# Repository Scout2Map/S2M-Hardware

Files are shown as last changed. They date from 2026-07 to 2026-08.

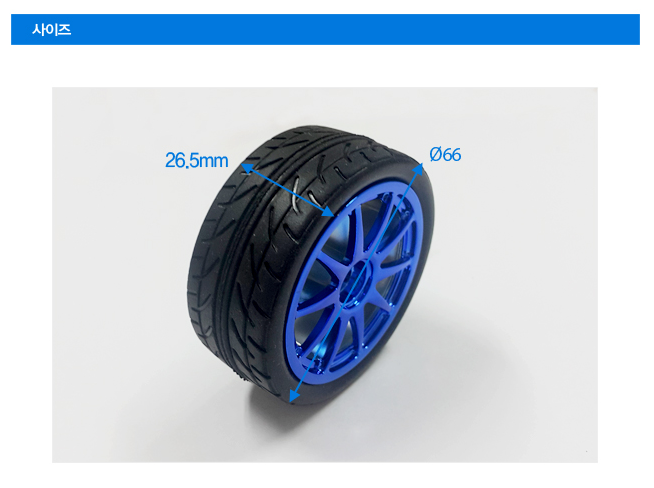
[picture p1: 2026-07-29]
electronics/Offroad 66pi Wheel.png

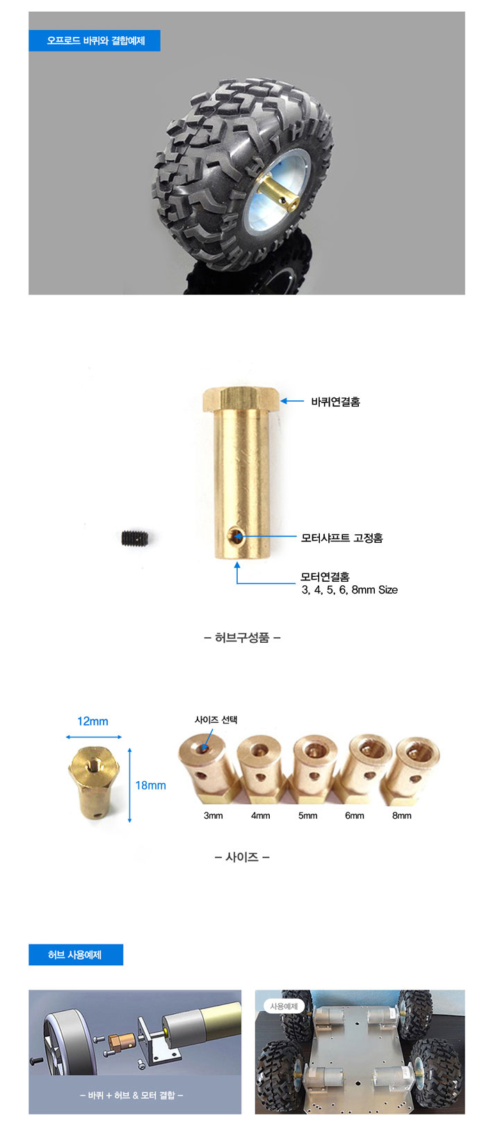
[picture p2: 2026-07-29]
electronics/Motor Hex Hub.png

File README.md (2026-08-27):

# S2M-Hardware

**Scout2Map** — 다중 센서 기반 환경 적응형 정찰 UGV의 하드웨어 설계 자료 저장소.

전자 부품 및 회로 정보는 [`electronics`](./electronics), 차체 설계 자료는 [`mechanical`](./mechanical), ROS2/Gazebo 시뮬레이션용 URDF-xacro 모델은 [`UGV_description`](./UGV_description)에 있다.

## 폴더 구조

```
S2M-Hardware/
├── electronics/            # 전자 부품 스펙, 회로도, 핀맵
├── mechanical/              # 차체 설계 도면, 가공 파일
├── UGV_description/         # ROS2 패키지: URDF-xacro 모델 + 시뮬레이션 에셋
│   ├── package.xml
│   ├── CMakeLists.txt
│   ├── urdf/
│   │   └── scout2map.urdf.xacro   # 로봇 모델 본체
│   ├── config/
│   │   └── bridge.yaml            # gz ↔ ROS2 토픽 브릿지 설정
│   ├── worlds/
│   │   ├── slip_test.world.sdf    # 요철·슬립 테스트용 월드
│   │   └── bump_field.png         # 요철 지형용 heightmap 이미지
│   └── launch/
│       ├── spawn_robot.launch.py       # 로봇 스폰 + robot_state_publisher + 브릿지
│       └── slip_test_world.launch.py   # slip_test 월드 실행
└── README.md
```

`UGV_description`은 실제 차체 치수를 기반으로 한 URDF-xacro 모델과, 이를 Gazebo에서 바로 돌려볼 수 있는 launch/world 파일 일체를 담은 독립 ROS2 패키지다. 디렉터리명은 `UGV_description`이지만 `package.xml` 상의 ROS2 패키지 이름은 `s2m_description`이다.

---

## 사용법 (UGV_description)

### 1. 워크스페이스에 배치 및 빌드

```bash
ln -s ~/S2M-Hardware/UGV_description ~/scout_sim_ws/src/UGV_description
cd ~/scout_sim_ws
colcon build --packages-select s2m_description
source install/setup.bash
```

### 2. 요철·슬립 테스트 월드 실행

```bash
ros2 launch s2m_description slip_test_world.launch.py
```

Gazebo가 뜨면 요철 지형(heightmap)과 저마찰 슬립 구역(파란 반투명 박스, x=3m 지점)이 보인다.

### 3. 로봇 스폰

월드가 뜬 상태에서 별도 터미널을 열어 로봇을 스폰한다. `robot_state_publisher`, `ros_gz_bridge`가 함께 실행되며 `/scan`, `/imu`, `/odom`, `/tf`, `/cmd_vel` 토픽이 ROS2 쪽으로 연결된다.

```bash
source /opt/ros/jazzy/setup.bash
source ~/scout_sim_ws/install/setup.bash
ros2 launch s2m_description spawn_robot.launch.py
```

필요 시 스폰 위치를 인자로 지정할 수 있다. `z_pose`(기본 0.05m)는 지면 간격(20mm)보다 살짝 높은 곳에서 떨어뜨려 물리엔진이 바퀴를 지면에 자연스럽게 안착시키기 위한 값이다.

```bash
ros2 launch s2m_description spawn_robot.launch.py x_pose:=0.5 y_pose:=0.0 z_pose:=0.05
```

### 4. 토픽 확인

```bash
ros2 topic list | grep -E "/(scan|imu|odom|cmd_vel|tf)"
ros2 topic echo /scan --once | head -20
```

이후는 `slam_toolbox` / `teleop_twist_keyboard`로 검증한다. `/cmd_vel`로 주행하면서 요철 구간과 슬립 구역 통과 시 `/odom` 대비 실제 이동량 괴리를 관찰하는 방식으로 슬립·요철 이벤트 판별 로직을 검증할 수 있다.

> `gz-sim-diff-drive-system` 플러그인 이름은 gz-sim 버전에 따라 다를 수 있다. 로봇이 스폰됐는데 `/cmd_vel`에 반응하지 않으면 `gz sim --plugin-path`로 실제 플러그인 파일명을 확인해 `urdf/scout2map.urdf.xacro`의 `<plugin filename=...>` 값을 맞춘다.

---

## 좌표계 정의

모든 치수는 `base_link` 원점을 기준으로 한다. `base_link` 원점은 **지면(z=0)** 이며, 차체 플랫폼 바닥면은 이 지면에서 20mm 띄워진다.

- x축: 전진 방향 (+)
- y축: 좌측 방향 (+)
- z축: 상방 (+)

지면 기준을 먼저 고정한다. `base_link`가 지면 자체이므로 차체 바닥면은 지면에서 20mm 띄워지며(`ground_clearance`), 바퀴는 반드시 이 지면에 접지해야 하므로 바퀴 축 높이는 `wheel_radius`(현재 33mm)와 동일하게 설정된다. 타이어를 바꿔 `wheel_radius`가 달라져도 바퀴가 항상 지면(`z=0`)에 닿도록 xacro 수식으로 연결해 두었다.

---

## 차체 본체 (base_link)

| 항목 | 값 |
|---|---|
| 크기 (L × W × H) | 265mm × 220mm × 110mm |
| 지면 간격 (ground clearance, 바닥면 → 지면) | 20mm |
| 지면 기준 전체 높이 (지면 → 차체 상단) | 130mm (20 + 110) |
| 질량 | 1800g |
| 무게중심 오프셋 (x, y, z) | (0, 0, 75mm) — 기하학적 중심 근사치 |
| 관성 텐서 | 아래 표 참조 (박스 근사) |

### 관성 텐서 (box 근사, 무게중심 기준)

| 성분 | 값 (kg·m²) |
|---|---|
| I_xx | 0.009075 |
| I_yy | 0.012349 |
| I_zz | 0.017794 |
| I_xy, I_xz, I_yz | 0 (좌우/전후 대칭 가정) |

---

## 바퀴 (wheel_link)

| 항목 | 값 |
|---|---|
| 바퀴 지름 | 66mm (반지름 33mm) |
| 바퀴 폭 | 26mm |
| 바퀴 질량 | 개당 35g |
| 트랙폭 (좌우 바퀴 중심 간 거리) | 240mm |
| 휠베이스 (전후 바퀴 중심 간 거리) | 140mm |
| 지면 간격 (플랫폼 바닥면 → 지면) | 20mm |
| 바퀴 축 높이 (지면 → 바퀴 축 중심, = 반지름) | +33mm |

### 바퀴 장착 위치 (지면 base_link 기준, 4륜 스키드 스티어)

| 바퀴 | x | y | z |
|---|---|---|---|
| front_left | +70mm | +120mm | +33mm |
| front_right | +70mm | −120mm | +33mm |
| rear_left | −70mm | +120mm | +33mm |
| rear_right | −70mm | −120mm | +33mm |

---

## 센서 장착 위치 (지면 base_link 기준)

### LiDAR (RPLiDAR C1)

| 항목 | 값 |
|---|---|
| 장착 위치 (x, y, z) | (0, 0, 130mm) — 지면 기준 |
| 회전 방향/오프셋 | (0, 0, 3.14159265), 정면 기준 180도 회전 보정 |
| 스캔 범위 | 0.05 ~ 12m, 360° |

### IMU (BNO055)

| 항목 | 값 |
|---|---|
| 장착 위치 (x, y, z) | (0, 0, 85mm) — 지면 기준 |

---

## Xacro 속성값 참조

`UGV_description/urdf/scout2map.urdf.xacro`에 아래 값이 `xacro:property`로 반영되어 있다. 치수 변경 시 이 표와 함께 xacro 파일도 갱신한다. (단위: m, kg, rad)

```xml
<!-- ground clearance defines the gap below chassis -->
<xacro:property name="ground_clearance" value="0.020"/>

<!-- chassis dimensions -->
<xacro:property name="chassis_length" value="0.265"/>
<xacro:property name="chassis_width"  value="0.220"/>
<!-- chassis height is 110mm to reach 130mm from ground -->
<xacro:property name="chassis_height" value="0.110"/>
<xacro:property name="chassis_mass"   value="1.8"/>

<!-- base_link is on the ground -->
<!-- wheel axle height is exactly the wheel radius -->
<xacro:property name="wheel_axle_z" value="${wheel_radius}"/>

<!-- sensor offsets relative to the ground -->
<!-- lidar sits on top of chassis at 130mm from ground -->
<xacro:property name="lidar_offset_z" value="0.130"/>
<!-- imu offset includes ground clearance -->
<xacro:property name="imu_offset_z"   value="0.085"/>

<!-- rotated using pi to fix orientation -->
<xacro:property name="lidar_yaw_offset" value="3.14159265"/>
```

---

## 시뮬레이션 참고 사항

- 정밀 3D mesh 없이 box/cylinder primitive geometry로 구성했다. Gazebo 물리엔진은 `<collision>` geometry 기준으로 동작하므로 시각적 mesh는 CAD 확정 시 교체해도 무방하다.
- 요철·슬립 지형은 Gazebo heightmap geometry(grayscale 이미지 기반 높낮이) 및 `<surface><friction><ode><mu>` 파라미터 조합으로 재현해 `worlds/slip_test.world.sdf`에 반영했다. 요철 구간은 heightmap, 슬립 구간은 별도 저마찰(mu=0.05) 박스로 분리 구성되어 있다.
- 4륜 스키드 스티어는 `gz-sim-diff-drive-system` 플러그인에 `left_joint`/`right_joint`를 각각 2개(front+rear)씩 등록하는 방식으로 구현했다.

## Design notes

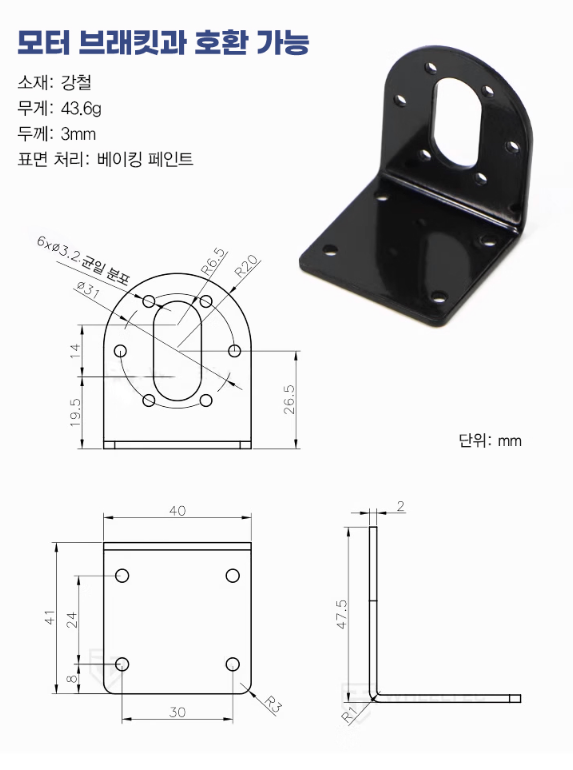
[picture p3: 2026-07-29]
electronics/JGB Motor Bracket.png

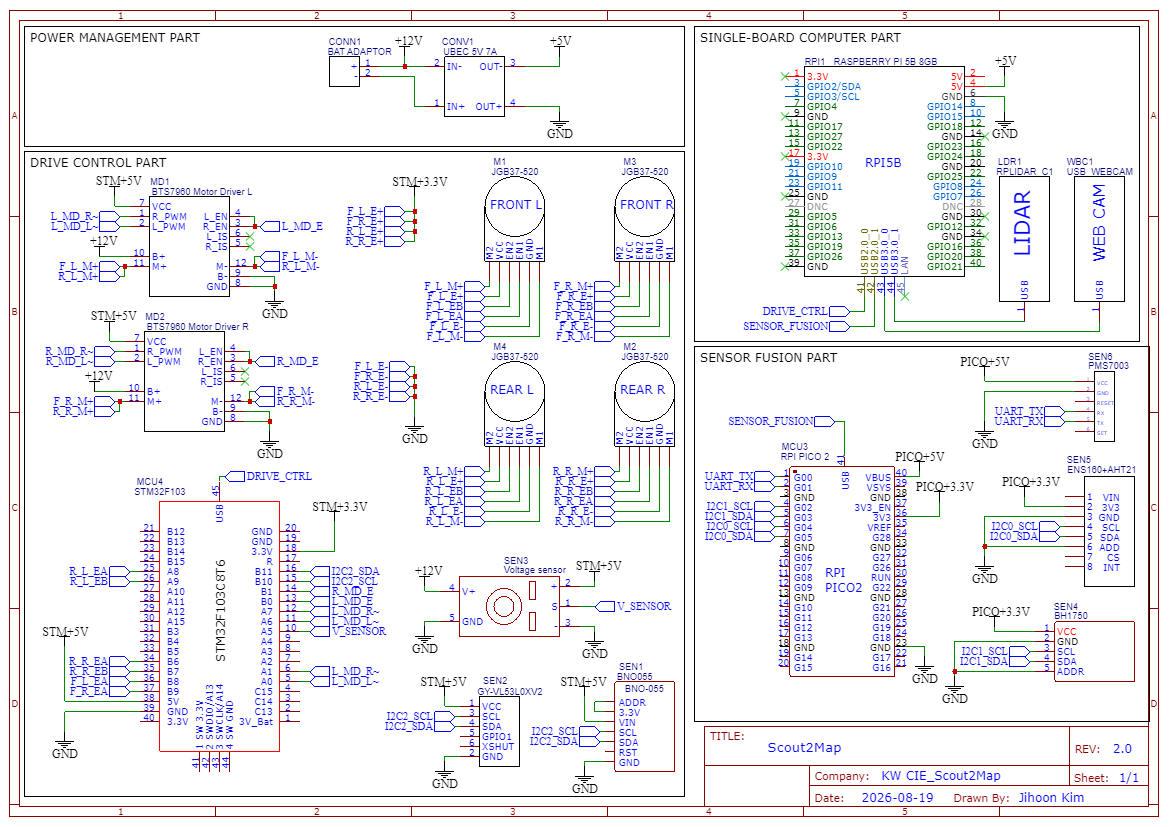
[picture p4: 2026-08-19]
schemetic/Schematic_Scout2Map.png

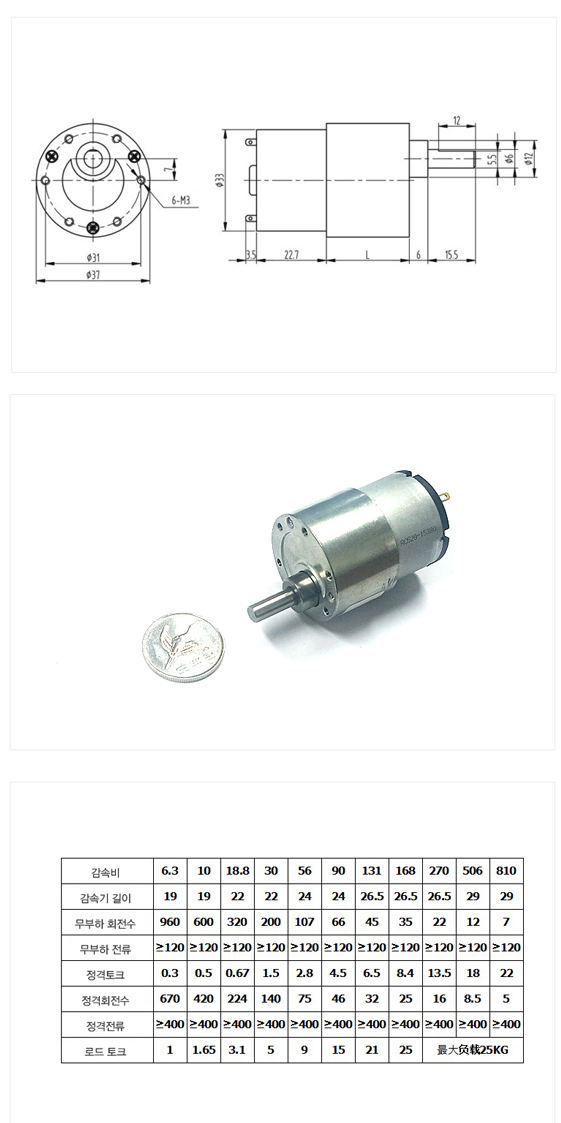
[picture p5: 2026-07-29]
electronics/JGB-520 Motor.png

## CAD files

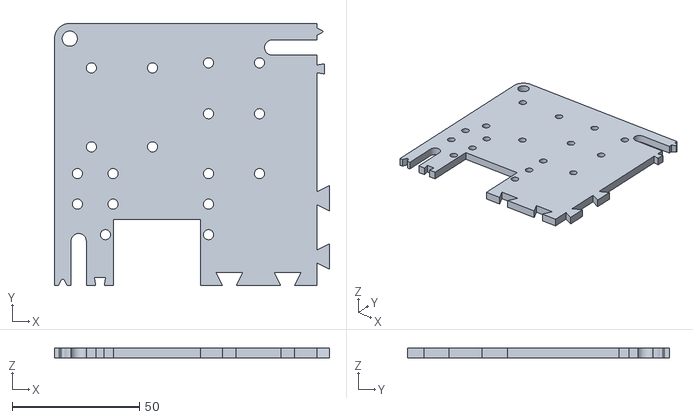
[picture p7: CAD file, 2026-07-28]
mechanical/MainPlatform/MainPlatform TL.stl
108.0 x 103.0 x 4.00

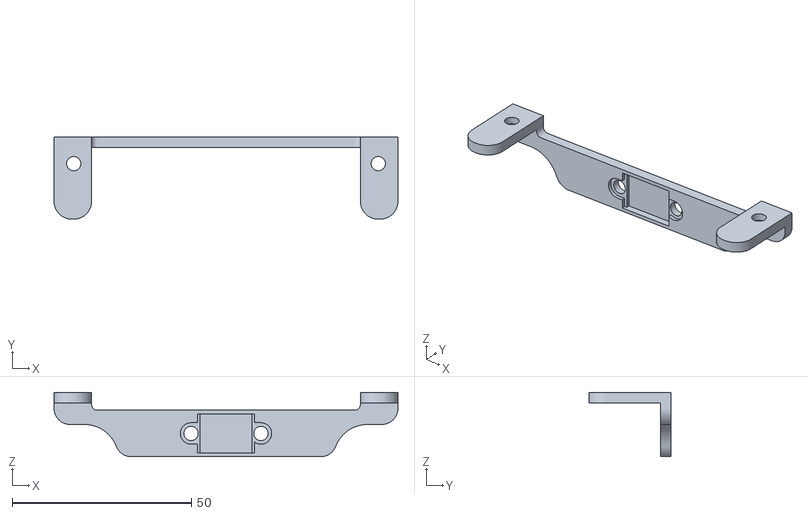
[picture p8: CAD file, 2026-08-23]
mechanical/MainPlatform/I2C DistSensor Holder.stl
96.0 x 23.0 x 18.0

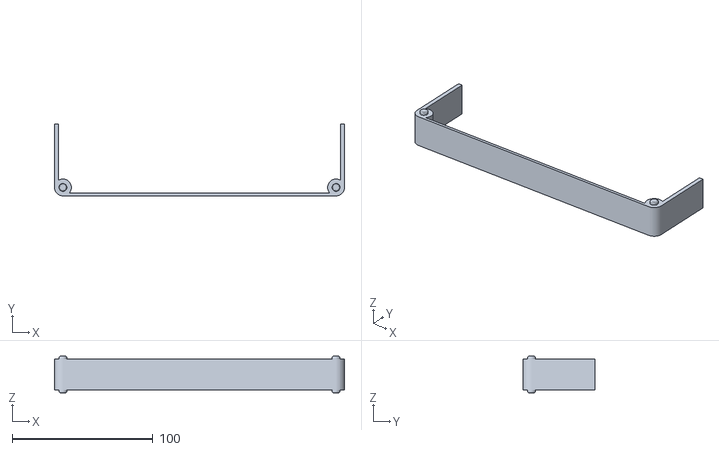
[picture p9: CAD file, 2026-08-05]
mechanical/RearPlate/Rear Wall.stl
206.0 x 51.0 x 26.0

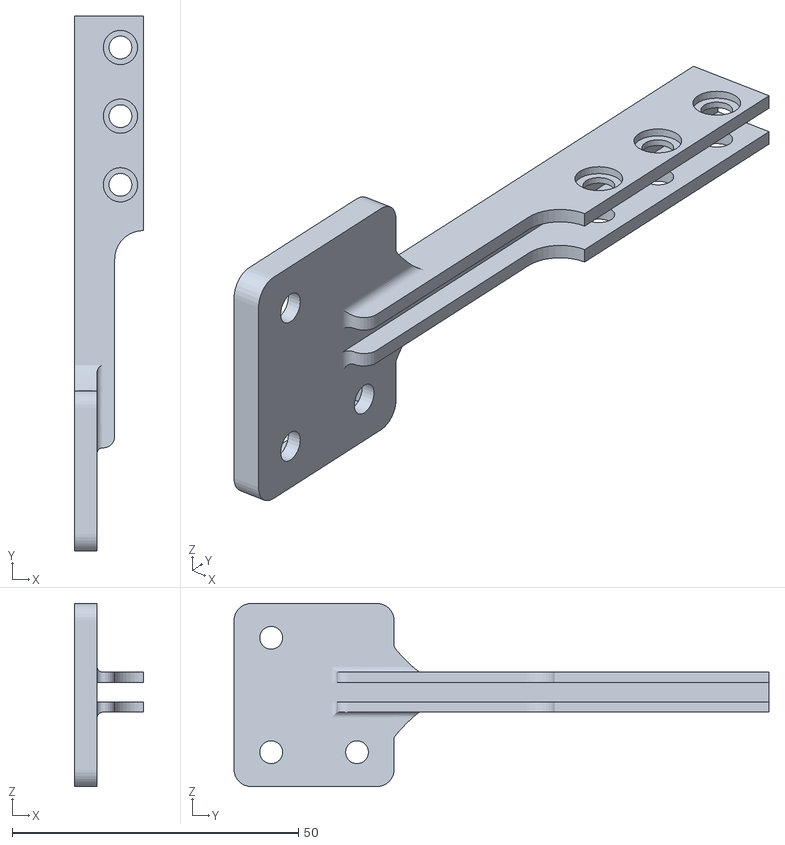
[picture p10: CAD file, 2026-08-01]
mechanical/TopPlate/EnvGasSensor Holder.stl
12.0 x 93.5 x 32.0

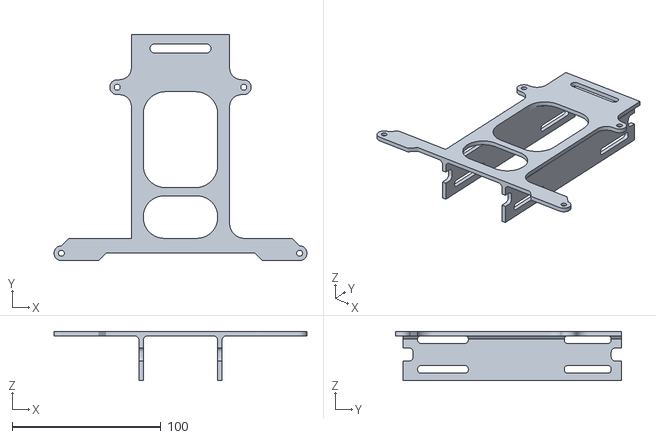
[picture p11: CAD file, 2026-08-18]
mechanical/MainPlatform/Battery Cover.stl
169.9 x 152.0 x 33.0

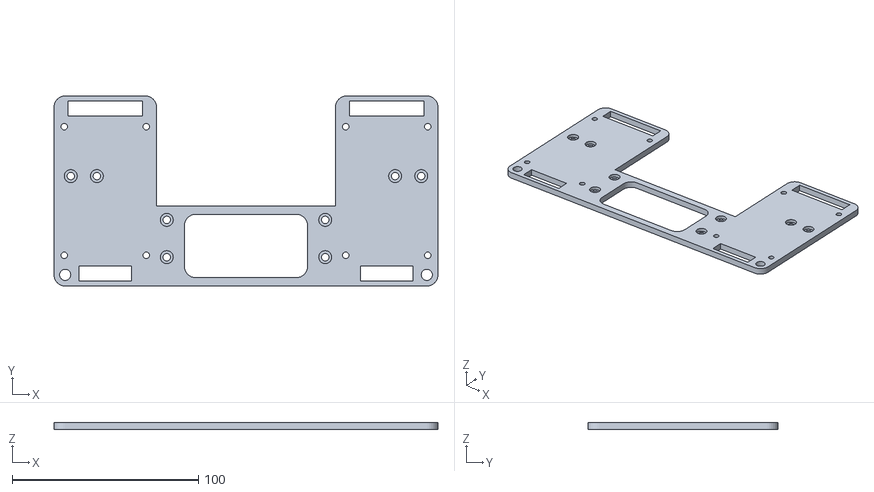
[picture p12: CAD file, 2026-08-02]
mechanical/RearPlate/RearPlate.stl
206.0 x 102.0 x 4.00

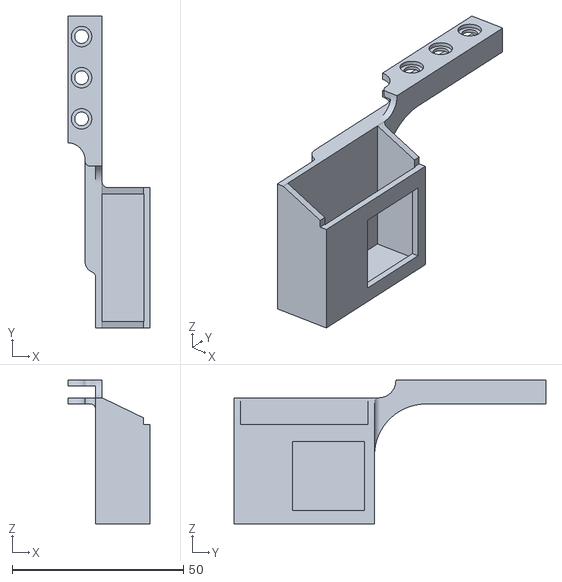
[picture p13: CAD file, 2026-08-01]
mechanical/TopPlate/DustSensor Holder.stl
24.0 x 91.0 x 42.0

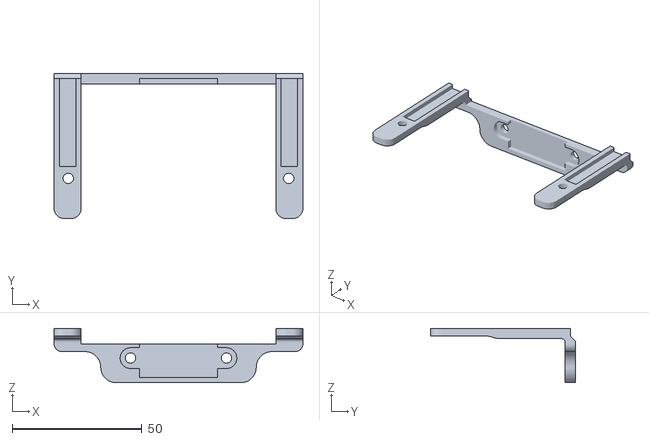
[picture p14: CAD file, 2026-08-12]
mechanical/MainPlatform/DistSensor Holder.stl
96.0 x 56.0 x 21.0

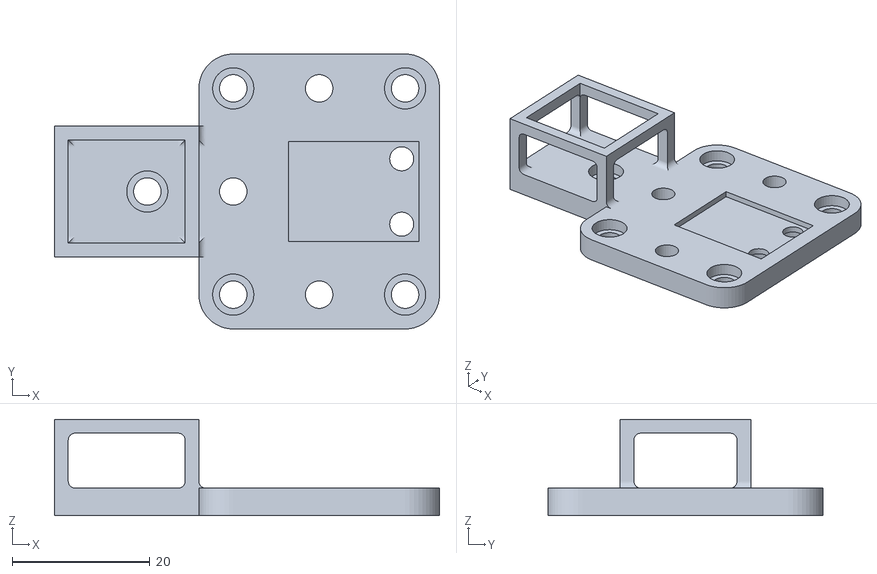
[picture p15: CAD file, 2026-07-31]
mechanical/TopPlate/LumiSensor Holder.stl
56.0 x 40.0 x 14.0

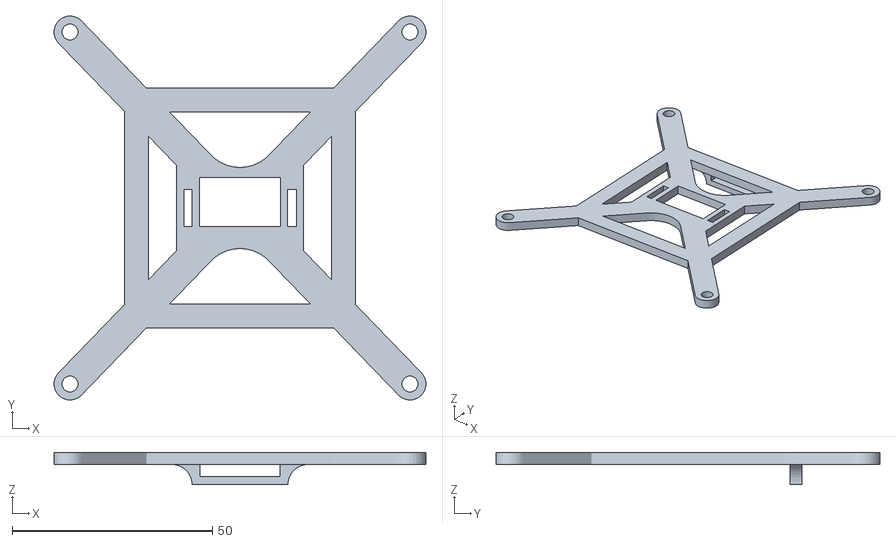
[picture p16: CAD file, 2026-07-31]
mechanical/MainPlatform/IMU Holder Plate.stl
93.0 x 96.0 x 8.00

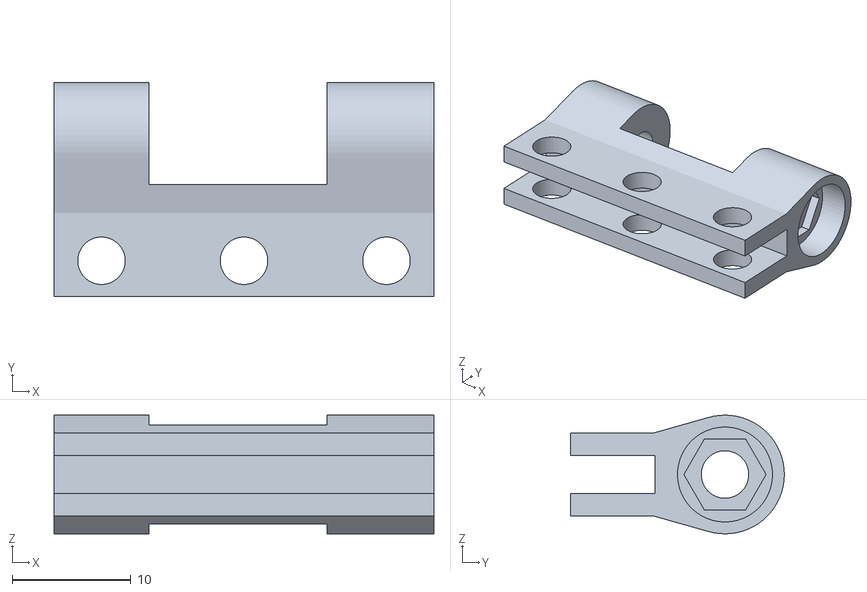
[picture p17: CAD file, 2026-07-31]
mechanical/TopPlate/Webcam Holder.stl
32.0 x 18.0 x 10.00

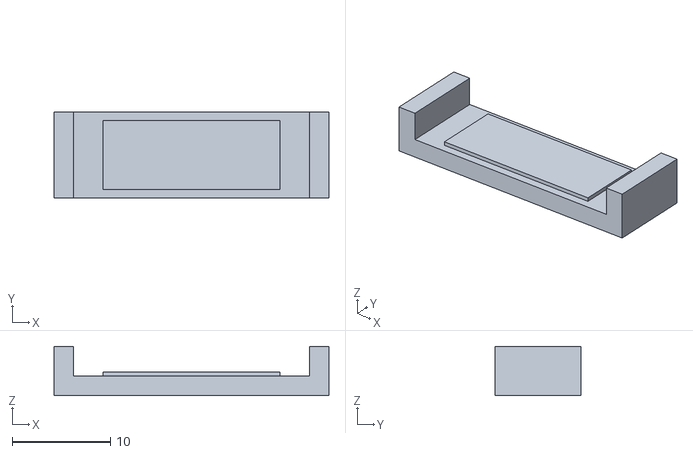
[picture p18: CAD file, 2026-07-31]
mechanical/MainPlatform/IMU Holder Cover.stl
28.0 x 8.80 x 5.00

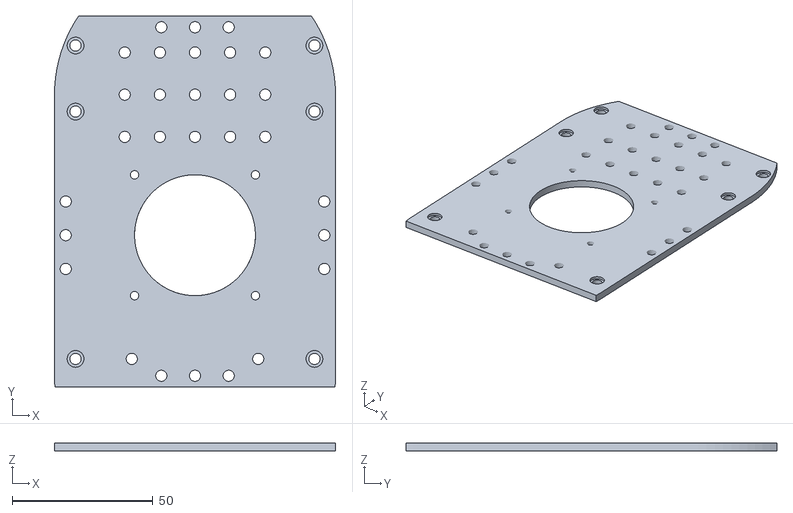
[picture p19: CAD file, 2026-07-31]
mechanical/TopPlate/Top Plate.stl
100.0 x 132.0 x 3.00

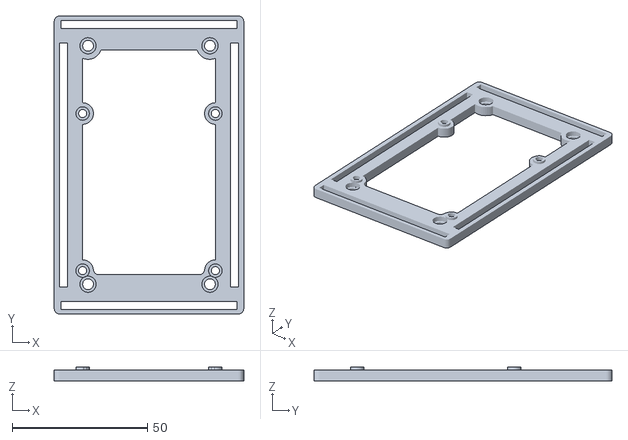
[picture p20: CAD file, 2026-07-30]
mechanical/MainPlatform/RPI Holder Plate.stl
70.0 x 110.0 x 5.00

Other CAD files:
mechanical/MainPlatform/MainPlatform BR.stl
mechanical/MainPlatform/MainPlatform BL.stl
mechanical/MainPlatform/MainPlatform TR.stl
mechanical/MainPlatform/Motor Driver Cover.stl
mechanical/MainPlatform/Connecting Bridge Sub.stl
mechanical/MainPlatform/Connecting Bridge.stl
mechanical/Scout2Map_UGV_Parts.f3d

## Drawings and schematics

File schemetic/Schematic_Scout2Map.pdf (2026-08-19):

# RPI5B USB2.0_1 42 USB3.0_0 43 USB3.0_1 44 USB2.0_0 41

## DRIVE CONTROL PART

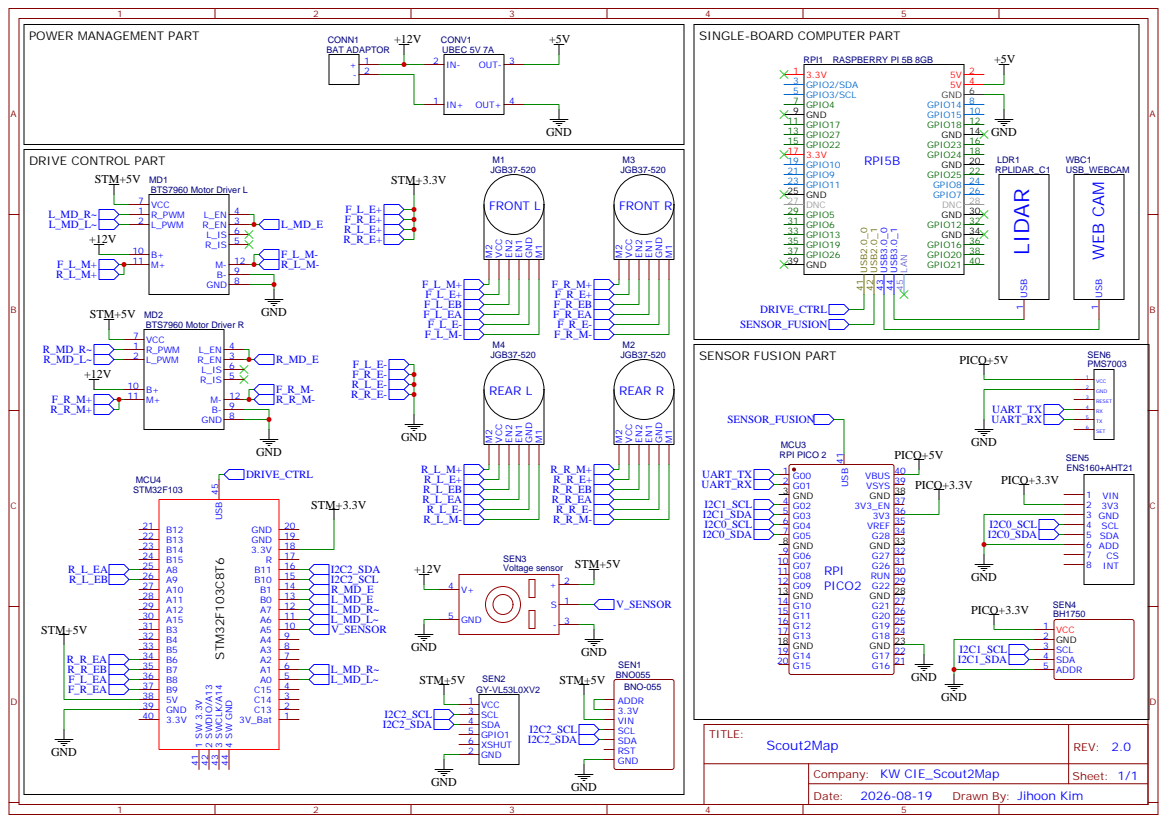
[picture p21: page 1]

Drawn By: Jihoon Kim

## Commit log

2026-07-28 Upload: main design file
    [Scout2Map_UGV_Parts.f3d]
2026-07-28 Upload: UGV's main platform printing file
    [MainPlatform BL.stl, MainPlatform BR.stl, MainPlatform TL.stl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]
2026-07-29 Update: connecting bridge
    [Connecting Bridge.stl, Scout2Map_UGV_Parts.f3d]
2026-07-30 Update: reinforce connecting bridge
    [Connecting Bridge Main.stl, Connecting Bridge Sub.stl, Scout2Map_UGV_Parts.f3d]
2026-07-30 Update: RPI board holder plate
    [RPI Holder Plate.stl, Scout2Map_UGV_Parts.f3d]
2026-07-30 Update: motor driver cover
    [Motor Driver Cover.stl, Scout2Map_UGV_Parts.f3d]
2026-07-30 Update: lightweighting RPI holder plate
    [RPI Holder Plate.stl, Scout2Map_UGV_Parts.f3d]
2026-07-30 Fix: incorrect design of the RPI holder plate
    [RPI Holder Plate.stl, Scout2Map_UGV_Parts.f3d]
2026-07-31 Update: top plate
    [Scout2Map_UGV_Parts.f3d, Top Plate.stl]
2026-07-31 Update: webcam holder
    [Scout2Map_UGV_Parts.f3d, Webcam Holder.stl]
2026-07-31 Update: change the Connecting Bridge to an IMU Holder
    [Connecting Bridge Main.stl, Connecting Bridge.stl, IMU Holder Cover.stl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]
2026-07-31 Fix: reinforcement of connections
    [IMU Holder Cover.stl, IMU Holder Plate.stl, Scout2Map_UGV_Parts.f3d]
2026-07-31 Update: expend clearance
    [IMU Holder Cover.stl, IMU Holder Plate.stl, Scout2Map_UGV_Parts.f3d]
2026-07-31 Update: LumiSensor Holder
    [LumiSensor Holder.stl, Scout2Map_UGV_Parts.f3d]
2026-07-31 Fix: expend cable holder
    [LumiSensor Holder.stl, Scout2Map_UGV_Parts.f3d]
2026-07-31 Update: Dust Sensor Holder
    [DustSensor Holder.stl, Scout2Map_UGV_Parts.f3d]
2026-07-31 Update: EnvGasSensor Holder
    [EnvGasSensor Holder.stl, Scout2Map_UGV_Parts.f3d]
2026-07-31 Update: lightweighting EnvGasSensor, DustSensor Holder
    [DustSensor Holder.stl, EnvGasSensor Holder.stl, Scout2Map_UGV_Parts.f3d]
2026-08-01 Fix: incorrect design of an Sensor Holders
    [DustSensor Holder.stl, EnvGasSensor Holder.stl, Scout2Map_UGV_Parts.f3d]
2026-08-01 Update: incorrect design of an Sensor Holders (2)
    [DustSensor Holder.stl, EnvGasSensor Holder.stl, Scout2Map_UGV_Parts.f3d]
2026-08-01 Update: incorrect design of an Sensor Holders (3)
    [DustSensor Holder.stl, EnvGasSensor Holder.stl, Scout2Map_UGV_Parts.f3d]
2026-08-01 Update: Distance Sensor Holder
    [DistSensor Holder.stl, Scout2Map_UGV_Parts.f3d]
2026-08-02 Update: lightweighting Distance Sensor Holder
    [DistSensor Holder.stl, Scout2Map_UGV_Parts.f3d]
2026-08-02 Update: Rear Plate
    [RearPlate.stl, Scout2Map_UGV_Parts.f3d]
2026-08-02 Fix: incorrect design of an Rear Plate
    [RearPlate.stl, Scout2Map_UGV_Parts.f3d]
2026-08-05 Update: Rear Wall
    [Rear Wall.stl, Scout2Map_UGV_Parts.f3d]
2026-08-05 Upload: UGV description pakage files for sim
    [scout2map.urdf.xacro, slip_test.world.sdf]
2026-08-12 Update: Expansion of clearance space for distance sensor holder
    [DistSensor Holder.stl, Scout2Map_UGV_Parts.f3d]
2026-08-18 Update: Battery Cover
    [Battery Cover.stl, Scout2Map_UGV_Parts.f3d]
2026-08-19 Upload: Schemetic files
    [Schematic_Scout2Map_Altium.schdoc]
2026-08-19 Fix: Wrong part name, numbers
    [Schematic_Scout2Map_Altium.schdoc]
2026-08-23 Update: I2C DistSensor Holder
    [I2C DistSensor Holder.stl, Scout2Map_UGV_Parts.f3d]
2026-08-23 Fix: wrong UGV xacro
    [scout2map.urdf.xacro]
2026-08-23 Fix: revert yaw
    [scout2map.urdf.xacro]
2026-08-23 Fix: wrong yaw value
    [scout2map.urdf.xacro]
2026-08-24 Fix: wrong xacro property value
    [scout2map.urdf.xacro]
